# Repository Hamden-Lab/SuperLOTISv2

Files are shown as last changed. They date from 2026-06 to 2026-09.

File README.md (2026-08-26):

# SuperLOTISv2
Repo containing code for SuperLOTIS upgrade (SOPHIA camera, Pfeiffer Vacuum Pump and INFICON Vacuum Gauge)

## TODO
- [X] correct the bug at initialization of clients
- [] reimplement email in except error management in report_loop method
- [] fits image header not populated as expected
- [] test to take dark once again

## Issues
- KS : SOPHIA camera does not work through the StarTech USB Hub. Probable cause(s): https://chatgpt.com/s/t_6a70db7d7ffc81919d7addffe3072537, but works through the single 15ft USB3.0 cable. Needs to buy another one I guess.

## Architecture
* Python scripts to control/command/communicate with devices directly are located in `drivers/`
* Intermediate socket-based interface are located in `clients/`
* Constants and other useful functions are located in `tools/`

## Requirements
* Miniconda + Python 3.14
* opcua: for the Pfeiffer Vacuum Pump
* pyserial: for the INFICON
* pylablib: for the SOPHIA camera
* paramiko: SSH session
* typing-extensions
* keyring
* astropy
* influxdb3-python
* influxdb3 : database for status storage
* grafana : service for monitoring purposes

## Create the conda environment from file
```
conda env create -f environment.yml
```
If new packages have been installed, export again the current env configuration to file:
```
conda export > environment.yml
```

## Activate the conda environment
```
conda activate superlotis
```

## Reinstall the package
```
pip install -e .
```

## TODO
- [] write a sample scheduler script to test with our local devices (pdu + pump...)
- [] testing the camera chiller driver
- [] manage the timing of the scheduler lines now, now + 30, etc.
- [X] why apache2 server installation has root access required to edit php pages ? fixed wit sladm user
- [] remember to include outlet address for all items on PDU to constants.py
- [] write a windows bat file script that create a bunch of CMD terminals for each device driver + client with colours and paths
- [] get attribute names for SOPHIA
- [] implement shutter/dark taking for SOPHIA.py
- [X] set up NTP time server for PDU in order to have correct timing for logs
- [X] timeout of pdu is only 10 minutes max before logging off (see page 63 timeout). KS extend it to 10 minutes from the default 3 minutes.
- [X] send attributes update to slotis status server
- [X] find a way to end the threads properly (both socket server and polling) 
- [X] how to keep data persistent on the scheduler socket server ?

## SLOTIS sockets architecture

- `scheduler_loader.pl` : reading the schedule scripts and sending it to the scheduler host server ran in slotis_scheduler.pl
- `slotis_scheduler.pl` : hosting all the commands that need to be executed during the observation night.
- `device_client.pl/py` : sending status information to the slotis_status_server + interpreting and transfering commands read from the slotis_scheduler (smart way = identifying FLAG + managing the execution time by comparing it with now to what is contained in the scheduler line) host server to the actual device through serial or ethernet.

## Scheduler script sample

```perl
# Specify the exact local time of execution
# as: second minute hour day_of_month month year offset_in_seconds,
# then include the command.
# e.g., "12 10 18 13 11 2004 0 SLOTIS TCS NEXTRA +183210.0" would be executed at Sat Nov 13 18:10:12 2004
# while "12 10 18 13 11 2004 21 SLOTIS TCS NEXTRA +183210.0" would be executed at Sat Nov 13 18:10:43 2004

# A negative offset is also possible.
# e.g.,  "12 10 18 13 11 2004 -3 SLOTIS TCS NEXTRA +183210.0" would be executed at Sat Nov 13 18:10:09 2004
} elsif ( $line =~ /(\d+)\s+(\d+)\s+(\d+)\s+(\d+)\s+(\d+)\s+(\d+)\s*([\-|\s])(\d+)\s+(.+)/ ) {
$sec = $1;
$min = $2;
$hour = $3;
$mday = $4;               # Day of the month
$mon = $5 - 1;            # Months from Time::Local are 0 to 11, this changes the range from 1 to 12 to 0 to 11.
$year = $6;
$sign = $7;
$offset_secs = $8;
$cmd = $9;
$offset_secs = 0 - $offset_secs if $sign =~ /\-/;

$unix_timestamp = timelocal($sec, $min, $hour, $mday, $mon, $year) + $offset_secs;
```

```bash
#Observing schedule for 230518
now -1 SLOTIS SICAM cooler on
now 0 SLOTIS TCS 4 MOVSTOW
now 1 SLOTIS TCS 4 DISEPOCH 2000.0
0 31 19 18 05 2023 -20 SLOTIS TCS 0 ELAZ 85.00 180.00
0 31 19 18 05 2023 -10 SLOTIS TCS 0 TRKON
0 31 19 18 05 2023 0 SLOTIS FILTER position 1
0 31 19 18 05 2023 1 SLOTIS SICAM object Flat_B
0 31 19 18 05 2023 41 SLOTIS SICAM setexp 2000
0 31 19 18 05 2023 44 SLOTIS SICAM expose
0 31 19 18 05 2023 67 SLOTIS SICAM wfits /home/slotis/data/230518/flat001.fits
0 31 19 18 05 2023 88 SLOTIS TCS 0 stepra 100
0 31 19 18 05 2023 98 SLOTIS SICAM setexp 3000
0 31 19 18 05 2023 101 SLOTIS SICAM expose
0 31 19 18 05 2023 125 SLOTIS SICAM wfits /home/slotis/data/230518/flat002.fits
0 31 19 18 05 2023 146 SLOTIS TCS 0 stepra 100
0 31 19 18 05 2023 156 SLOTIS SICAM setexp 3000
0 31 19 18 05 2023 159 SLOTIS SICAM expose
0 31 19 18 05 2023 183 SLOTIS SICAM wfits /home/slotis/data/230518/flat003.fits
0 31 19 18 05 2023 204 SLOTIS TCS 0 stepra 100
0 31 19 18 05 2023 214 SLOTIS SICAM setexp 4000
0 31 19 18 05 2023 217 SLOTIS SICAM expose
0 31 19 18 05 2023 242 SLOTIS SICAM wfits /home/slotis/data/230518/flat004.fits
0 31 19 18 05 2023 263 SLOTIS TCS 0 stepra 100
0 31 19 18 05 2023 273 SLOTIS SICAM setexp 5000
0 31 19 18 05 2023 276 SLOTIS SICAM expose
0 31 19 18 05 2023 302 SLOTIS SICAM wfits /home/slotis/data/230518/flat005.fits
0 31 19 18 05 2023 323 SLOTIS TCS 0 stepra 100
0 31 19 18 05 2023 333 SLOTIS FILTER position 2
0 31 19 18 05 2023 334 SLOTIS SICAM object Flat_V
0 31 19 18 05 2023 374 SLOTIS SICAM setexp 3000
0 31 19 18 05 2023 377 SLOTIS SICAM expose
```

### SOPHIA get all attributes response

```python
Dictionary('ADC Analog Gain': High
'ADC Bit Depth': 16
'ADC Quality': Low Noise
'ADC Speed': 1.0
'Active Bottom Margin': 3
'Active Height': 2048
'Active Left Margin': 50
'Active Right Margin': 50
'Active Shutter': None
'Active Top Margin': 2
'Active Width': 2048
'CCD Characteristics': Back Illuminated & U.V. Enhanced & Multi-Port
'Clean Cycle Count': 1
'Clean Cycle Height': 2048
'Clean Serial Register': True
'Clean Until Trigger': True
'Cooling Fan Status': On
'Correct Pixel Bias': True
'Disable Cooling Fan': False
'Disable Data Formatting': False
'Exact Readout Count Maximum': 1000000000000
'Exposure Time': 100.0
'External Shutter Status': Not Connected
'External Shutter Type': Vincent CS45
'Frame Rate Calculation': 0.22867631860928136
'Frame Size': 8388608
'Frame Stride': 8388608
'Frame Tracking Bit Depth': 64
'Frames per Readout': 1
'Gap Height': 0.0
'Gap Width': 0.0
'Internal Shutter Status': Not Connected
'Internal Shutter Type': Vincent CS45
'Invert Output Signal': False
'Invert Output Signal-2': False
'Kinetics Window Height': 10
'Online Readout Rate Calculation': 0.23402798440173528
'Orientation': Normal
'Output Signal': Exposing
'Output Signal-2': Reading Out
'Pixel Bit Depth': 16
'Pixel Format': Monochrome 16-bit
'Pixel Height': 13.5
'Pixel Width': 13.5
'ROIs': [CPicamRoi(x=0, width=2048, x_binning=1, y=0, height=2048, y_binning=1)]
'Readout Control Mode': Full Frame
'Readout Count': 1
'Readout Orientation': Normal
'Readout Port Count': 1
'Readout Rate Calculation': 0.22867631860928136
'Readout Stride': 8388608
'Readout Time Calculation': 4272.99326
'Sensor Active Bottom Margin': 3
'Sensor Active Extended Height': 0
'Sensor Active Height': 2048
'Sensor Active Left Margin': 50
'Sensor Active Right Margin': 50
'Sensor Active Top Margin': 2
'Sensor Active Width': 2048
'Sensor Masked Bottom Margin': 0
'Sensor Masked Height': 0
'Sensor Masked Top Margin': 0
'Sensor Secondary Active Height': 0
'Sensor Secondary Masked Height': 0
'Sensor Temperature Reading': 19.0
'Sensor Temperature Set Point': 25.0
'Sensor Temperature Status': Unlocked
'Sensor Type': CCD
'Shutter Closing Delay': 0.0
'Shutter Delay Resolution': 1000.0
'Shutter Opening Delay': 0.0
'Shutter Timing Mode': Normal
'Time Stamp Bit Depth': 64
'Time Stamp Resolution': 10000000
'Time Stamps': None
'Track Frames': False
'Trigger Determination': Rising Edge
'Trigger Response': No Response
'Vertical Shift Rate': 12.0)
```

### Populate the headers of FITS images taken by SOPHIA from the status server

INSTRUMENT = 'SuperLOTIS telescope'
CCDNAME = 'Princeton Instruments E2V'
CCDTEMP
CCDTARGETTEMP
CHILLERTEMP
PUMP_PRESSURE
CAM_PRESSURE
VACUUM_VALVE
PDU_OUT1...
EXPTIME
DATE-OBS
MJD
FILTER
MOUNTRA
MOUNTDEC
MOUNTHA
MOUNTALT
MOUNTAZ
OBJECT
AIRMASS
WEATHER_...
CCDGAIN
BINNING
SHUTTER_STATUS
IMTYPE : light, dark, bias, flat...

+ all the attributes from SOPHIA with cam.get_all_attribute_values()

## Forward status and scheduler ports

ssh -L 5134:localhost:5134 -L 5135:localhost:5135 slotis@slotis.kpno.noirlab.edu

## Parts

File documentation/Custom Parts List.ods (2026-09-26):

Part | Material | Tolerance | Surface finish | Quantity | Drawing filename | Modify existing part? | Notes
Shutter controller plate | Aluminum 6061 | 0.01”, 0.002” for bolt holes | Deburred, as machined | 1 | shutter_controller_plate.pdf | N
LRS75 and USB hub plate | Aluminum 6061 | 0.01”, 0.002” for bolt holes | Deburred, as machined | 1 | lrs75_plate.pdf | N
90 deg breadboard bracket | Aluminum 6061 | 0.01”, 0.002” for bolt holes | Deburred, as machined | 4 | 90deg_bracket_tslot.pdf | N
Side breadboard bracket | Stainless steel | 0.01”, 0.002” for bolt holes | Deburred, as machined | 3 | side_bracket_tslot.pdf | N
Filter interface | Aluminum 6061 | 0.01”, 0.002” for bolt holes | Deburred, as machined | 1 | Filter_Interface_REAL.pdf | Y | Already exist, we bring it
G10 plate | Garolite G10 | 0.01”, 0.002” for bolt holes | Deburred, as machined | 1 | g10_camera_isolation_plate.pdf | Y | We bring the raw material
For questions, contact:
hmbradley1@arizona.edu
sommerk@arizona.edu

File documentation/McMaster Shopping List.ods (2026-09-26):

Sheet: Framing
 |  |  | McMaster ref. | From 8020 | Name 8020 | Comment
Count | Item | Length (in) | ID | No.
2 | Double | 12 | 47065T472 | 1020-Black | 1.00” X 2.00” T-Slotted Profile - Six Open T-Slots | Tap the holes 1/4-20
2 | Double | 38 |  | 1020-Black | 1.00” X 2.00” T-Slotted Profile - Six Open T-Slots | Tap the holes 1/4-20
Total Double | Double | 100
5 | Single | 10 | 47065T1 | 1010-Black | 1.00” X 1.00” T-Slotted Profile - Four Open T-Slots | Tap the holes 1/4-20
12 | Single | 12 | 47065T503 | 1010-Black | 1.00” X 1.00” T-Slotted Profile - Four Open T-Slots | Tap the holes 1/4-20
Total Single | Single | 194

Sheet: Brackets
Cage Assembly |  | McMaster ref. | From 8020 | Name 8020 | Comment
Count | Item | ID | No.
2 | Double L Bracket | 47065T562 | 4128-Black | 10 Series 12 Hole - 90 Degree Angled Flat Plate | Need to add fasteners
8 | 1x1 corner bracket | 47065T377 | 4265-Black | 10 Series 2 Hole - Slotted Inside Corner Bracket | Need to add fasteners
4 | 6” single diagonal brace | 47065T451 | 2565-Black | 1010-Black 45 Degree Support, 6" Long | Fasteners included
26 | 2Lx1W gusset | 47065T749 | 4136-Black | 10 Series 4 Hole - Tall Gusseted Inside Corner Bracket | Need to add fasteners
2 | 12” single diagonal brace | 47065T452 | 2570-Black | 1010-Black 45 Degree Support, 12" Long | Fasteners included
4 | T-Slotted Framing Black Straight Surface Bracket, 2" Long for 1" High Rail | 47065T832 | 4107-Black | 10 Series 2 Hole - Straight Flat Plate | Need to add fasteners
2 | T-Slotted Framing Black Surface Bracket, 4" Long for 1" High Single Rail | 47065T313 | 4117-Black | 10 Series 4 Hole - Straight Flat Plate | Need to add fasteners
Shutter Assembly Att.
2 | 1x1 corner bracket | 47065T377 | 4265-Black | 10 Series 2 Hole - Slotted Inside Corner Bracket | Need to add fasteners

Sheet: Fasteners
Camera Sub-assembly
Number | Screw | ID | Pack size
6 | 1/4”-20x1.5” HS | 96006A727 | 10
4 | 6-32x3/4” | 92196A151 | 100
6 | ¼” washer Narrow | 90313A203 | 50
20 | ¼” washer | 92141A029 | 100
6 | Nylon Flat Edge Insulating Sleeve Washers | 91145A222 | 100
1 | 3225T63_Vibration-Damping Loop Clamp | 3225T63 | 5 | Alternative is aluminum = 3177T11
Cage Assembly
Number | Screw
60 | T-slot Nut | 6000N501 | 4
Turbo Assembly
Number | Screw
6 | 1/4”-20x0.5” (socket head) | 92196A537 | 50 | HAVE
2 | 1/4”-20x5/8” |  |  | HAVE
4 | M5x16mm | 91292A126 | 100
Powerpak Assembly
Number | Screw
4 | 1/4”-20x0.5” (socket head) | 92196A537 | 50 | HAVE
Shutter Power USB Assembly
4 | Corrosion-Resistant 18-8 Stainless Steel Female Threaded Hex Standoff 1/4" Hex Size, 3-1/2" Long, 10-32 Thread Size | 91115A840 | 1
4 | 10-32x0.5” |  |  | HAVE
4 | 1/4”-20x0.75” |  |  | HAVE
MVP Assembly
4 | Vibration-Damping Sandwich Mount | 9376K36 | 1 | Need to cut one side of the male thread to fit in the T-slot groove
4 | High-Strength Steel Nylon-Insert Locknut | 97135A210 | 25

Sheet: Miscellaneous
Vacuum electrical insulation
1 | Edwards Swing Clamp, KF 16 (NW 16), Polymer, C10512304 | Edwards Swing Clamp, KF-16 (NW-16), Polymer Vacuum Clamp, C10512304, C105-12-304,Edwards Swing Clamp, KF-16 (NW-16), Polymer Vacuum Clamp, C10512304, C105-12-304 (https://www.ajvs.com/edwards-swing-clamp-23876)
1 | Pfeiffer Centering Ring KF-16 Vacuum Fittings, ISO-KF Flange Size NW-16, PTFE & Viton O-Ring. PN: 132ZRG016 | Ideal Vacuum | Pfeiffer Centering Ring KF-16 Vacuum Fittings, ISO-KF Flange Size NW-16, PTFE & Viton O-Ring. PN: 132ZRG016. (https://www.idealvac.com/en-us/Pfeiffer-Centering-Ring-KF-16-Vacuum-Fittings-ISO-KF-Flange-Size-NW-16-PTFE-Viton-O-Ring-PN:-132ZRG016/pp/P1012264)

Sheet: Custom parts
Custom Items
Camera Assembly |  |  | Drawings | Make at GS
Count | Item | Note
1 | tubing support frame | Strong 3D printed material
1 | Filter interface | Machine new holes + widen to fit the insulation sleeves to 0.312” at least | Kelian | Y
1 | G10 plate |  | Kelian | Y
Turbo Assembly
Count | Item
1 | Turbo_mounting_bracket | Aluminum machining + 3d print for circular shape | Harrison | Y
1 | Turbo_bottom_bracket | Aluminum machining | Harrison | Y
Cage Assembly
Count | Item
3 | side_bracket_tslot | Do we need stainless steel or alu is strong enough? | Kelian | Y
4 | 90deg_bracket_tslot | Buy a aluminum cube, cut in half and then CNC machine? | Kelian | Y
 | Tap 1/4”-20 holes in all of them |  |  | Y
Pump Electronics Assembly
Count | Item
4 | Tap 1/4”-20 holes in bottom |  |  | Y
Powerpak Assembly
2 | TELEDYNE_POWERPAK_BRACKET_V3 | Strong 3D printed material |  | N
Shutter Power USB Assembly
1 | shutter_controller_plate | Aluminum machining | Kelian | Y
1 | lrs75_plate | Aluminum machining | Kelian | Y
Enclosure
? | Clear Scratch- and UV-Resistant Cast Acrylic Sheet 24" x 24" x 1/8" | 85635K481 | Clear acrylic sheet or opaque PVC? What about blocking IR for the camera?

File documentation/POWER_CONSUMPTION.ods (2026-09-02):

Item | Ref. of device or PSU | Max power (W) | PDU outlet #
Following items are plugged into the YPS SRT1500RMXLA 1350W
Telescope mount |  | ? | N.A
Should we get a UPS for these two also ?
lyman computer | Dell Vostro 5890 | 460 | N.A
Camera power supply | SOPHIA Teledyne Powerpak | 410 | N.A
Following items are plugged into the PDU41001
INFICON gauge for camera | Meanwell LRS-50-24 | 50 | 3
INFICON gauge for pump | Meanwell LRS-50-24 | 50 | 4
ElectroMAG Vacuum valve | Meanwell LRS-75-24 | 75 | 2
Shutter controller | Uniblitz VCM-D1 | 60 | 8
Startech USB HUB ST1030USBM | Meanwell LRS-75-24 | 75 | 5
Vacuum pumps | Pfeiffer HiCube 80 Neo | 205 | 6
Camera chiller | TCube edge 10-14072-4S-1 | 850 | 7
 | Total (max) on PDU41001 | 1365
 | PDU rated for 1440W max

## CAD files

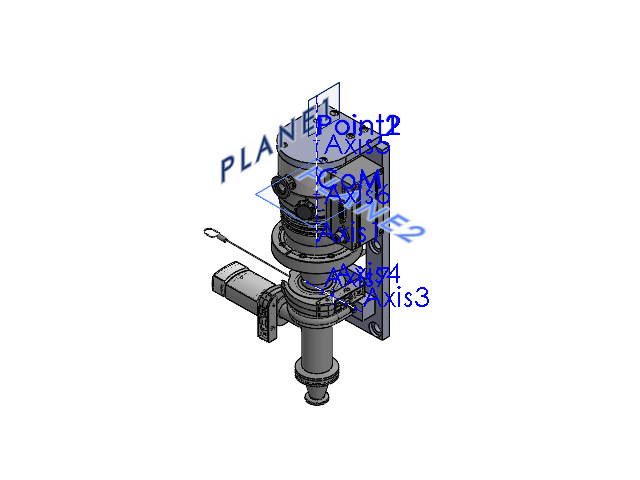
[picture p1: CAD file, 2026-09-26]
documentation/CAD/Turbo_bracket_assembly.SLDASM
Pfeiffer_HiPace_80_with_ISO63_PMP03940_Step_File.step
Turbo_mounting_bracket
Turbo_bottom_bracket
4518K614_Quick-Clamp High-Vacuum Fitting
4518K817_O-Ring with Stainless Steel Screen for 1-1-2 Tube OD Quick-Clamp High-Vacuum Fitting x 2
4518K522_Quick-Clamp High-Vacuum Fitting
3176T14_Vibration-Damping U-Bolt
4518K967_Lever Clamp with Lanyard
4518K621_Fluoroelastomer Rubber O-Ring for 3-4 Tube OD Quick-Clamp High-Vacuum Fitting
MPCG55x_15DSub_16KF.stp
4518K965_Lever Clamp with Lanyard
4518K291_Quick-Clamp High-Vacuum Fitting
socket head cap screw_am x 5
socket head cap screw_ai x 2

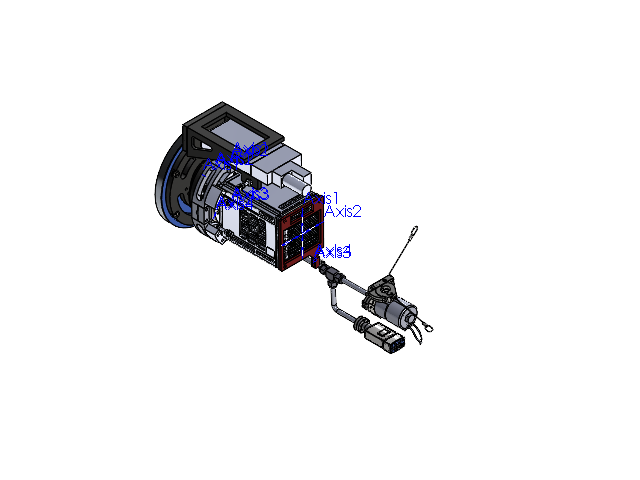
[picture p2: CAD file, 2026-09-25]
documentation/CAD/camera_assembly/UArizona_Superlotis_Assembly.SLDASM
Bracket
Filter_Interface_REAL
Interacing_Plate_LinearStage_to_FixtureHolder
LinearStage
LinearStage_Moving_Plate
Cosmetic_Flap x 4
OuterAssembly_Flexture_Holder_Long_End
OuterAssembly_Flexture_Holder_Short_End
OuterAssembly
teflon washer
AdjustmentScrew x 4
AdjustmentScrew_Mount x 2
AdjustmentScrew_ThreadBody x 4
Q27031-1 University of Arizona1(2)^custom_viewport_correct
custom_viewport_main
Q27031-1 University of Arizona3(2)^custom_viewport_correct
cs45-unhoused-3d-model1^cs45-unhoused-3d-model(2)_cs45-unhoused-3d-model
cs45-unhoused-3d-model2^cs45-unhoused-3d-model(2)_cs45-unhoused-3d-model
cs45-unhoused-3d-model3^cs45-unhoused-3d-model(2)_cs45-unhoused-3d-model
cs45-unhoused-3d-model4^cs45-unhoused-3d-model(2)_cs45-unhoused-3d-model
cs45-unhoused-3d-model5^cs45-unhoused-3d-model(2)_cs45-unhoused-3d-model
cs45-unhoused-3d-model6^cs45-unhoused-3d-model(2)_cs45-unhoused-3d-model
cs45-unhoused-3d-model7^cs45-unhoused-3d-model(2)_cs45-unhoused-3d-model
cs45-unhoused-3d-model8^cs45-unhoused-3d-model(2)_cs45-unhoused-3d-model
cs45-unhoused-3d-model9^cs45-unhoused-3d-model(2)_cs45-unhoused-3d-model
cs45-unhoused-3d-model10^cs45-unhoused-3d-model(2)_cs45-unhoused-3d-model
cs45-unhoused-3d-model11^cs45-unhoused-3d-model(2)_cs45-unhoused-3d-model
cs45-unhoused-3d-model12^cs45-unhoused-3d-model(2)_cs45-unhoused-3d-model
cs45-unhoused-3d-model13^cs45-unhoused-3d-model(2)_cs45-unhoused-3d-model
cs45-unhoused-3d-model14^cs45-unhoused-3d-model(2)_cs45-unhoused-3d-model
cs45-unhoused-3d-model15^cs45-unhoused-3d-model(2)_cs45-unhoused-3d-model
cs45-unhoused-3d-model16^cs45-unhoused-3d-model(2)_cs45-unhoused-3d-model
cs45-unhoused-3d-model17^cs45-unhoused-3d-model(2)_cs45-unhoused-3d-model
cs45-unhoused-3d-model18^cs45-unhoused-3d-model(2)_cs45-unhoused-3d-model
cs45-unhoused-3d-model19^cs45-unhoused-3d-model(2)_cs45-unhoused-3d-model
cs45-unhoused-3d-model20^cs45-unhoused-3d-model(2)_cs45-unhoused-3d-model
cs45-unhoused-3d-model21^cs45-unhoused-3d-model(2)_cs45-unhoused-3d-model
cs45-unhoused-3d-model22^cs45-unhoused-3d-model(2)_cs45-unhoused-3d-model
cs45-unhoused-3d-model23^cs45-unhoused-3d-model(2)_cs45-unhoused-3d-model
cs45-unhoused-3d-model24^cs45-unhoused-3d-model(2)_cs45-unhoused-3d-model
cs45-unhoused-3d-model25^cs45-unhoused-3d-model(2)_cs45-unhoused-3d-model
cs45-unhoused-3d-model26^cs45-unhoused-3d-model(2)_cs45-unhoused-3d-model
cs45-unhoused-3d-model27^cs45-unhoused-3d-model(2)_cs45-unhoused-3d-model
cs45-unhoused-3d-model28^cs45-unhoused-3d-model(2)_cs45-unhoused-3d-model
cs45-unhoused-3d-model29^cs45-unhoused-3d-model(2)_cs45-unhoused-3d-model
cs45-unhoused-3d-model30^cs45-unhoused-3d-model(2)_cs45-unhoused-3d-model
cs45-unhoused-3d-model32^cs45-unhoused-3d-model(2)_cs45-unhoused-3d-model
cs45-unhoused-3d-model33^cs45-unhoused-3d-model(2)_cs45-unhoused-3d-model
Flagen_adpater_L_2 x 2
6035-0004 SOPHIA-XO 2048 6 inch_1-300_Long.STEP_1 x 2
2517- 6-00 Conflat SOPHIA-XO 2048 6 inch-0.STEP_1
2825-0587 SOPHIA-XO 2048 6 inch.STEP_1 x 3
2825-0395-FLANGE SOPHIA-XO 2048 6 inch.STEP_1
2825-0395-SEAL SOPHIA-XO 2048 6 inch.STEP_1
Conflat 6-00 Nose SOPHIA-XO 2048 6 inch.STEP_1
CCD-230-42_2048x2048 SOPHIA-XO 2048 6 inch.STEP_1
PIXIS-II X-Ray Mask Large Array SOPHIA-XO 2048 6 inch.STEP_1
X-Ray Mask Large Array Clamp SOPHIA-XO 2048 6 inch.STEP_1
SCREW,FLAT HD,SLOT,VENTED,#2-56 x 0.1875,18-8 ST-STL SOPHIA-XO 2048 6 inch_2826-XXXX.STEP_1 x 4
2100-0678 SOPHIA-XO 2048 6 inch.STEP_1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

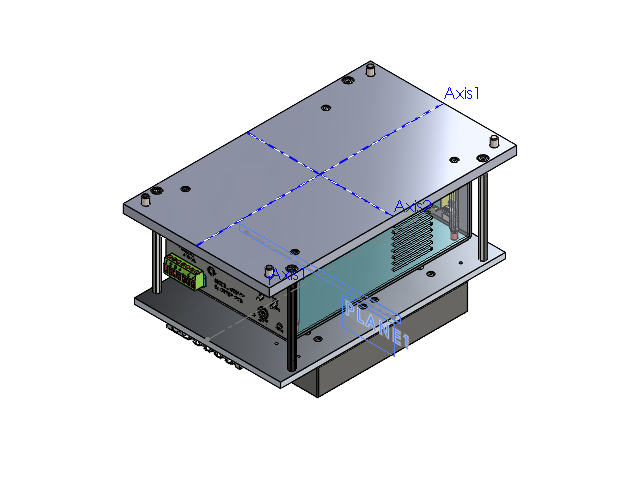
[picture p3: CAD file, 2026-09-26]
documentation/CAD/shutter_power_usb_assembly_V2.SLDASM
shutter_controller_plate
Slideswitchspdt2.STEP x 8
Keyswitch_Assembly.STEP
5-pinharness_9-pin.STEP
Keyswitchcable_Short.STEP
Cabletie_2wires short.STEP
VCM-D1fpsilk.STEP
Logo_Scale VCM-D1.STEP
Rochester.STEP
VA.STEP
VCM-D1_1.STEP
New logo 3D_VDM1000.STEP
VCM-D1case_With rp stud.STEP
BNC.STEP x 6
BNCnut.STEP x 6
groundlug.STEP x 6
Corcompower_115 V Closed.STEP
BNCgroundlug_Trimmed.STEP
Ledclip.STEP x 4
Keyswitchnut.STEP
Foot.STEP x 4
VCM-D1spacer.STEP
VCM-D1rpsilk.STEP
VCM-D1serialnolabel.STEP
VCM-D1metlabel.STEP
SwitchcraftTiniQG.STEP
3-48 x .1875 FH_CR-FHMS 0.099-48x0.188x0.188-S.STEP x 2
1-2-20hexnut_.255thick.STEP
6-32 Nut Hex_.109 thick.STEP x 2
Led.STEP x 4
Terminalsocket_7.STEP
Octalswitch.STEP
Inout.STEP
Fuseholderbottom.STEP
Corcom Fuse.STEP
Fuseholdercap.STEP
Switch_D3-D4.STEP x 2
Switch_D1-T1.STEP
Poststripplug_7.STEP
VCM-D1alignmentpl.STEP
VCM-D1cover.STEP
6-32mfstandoff.STEP x 4
Washer.STEP x 4
Corcomlabel.STEP
91115A840_Corrosion-Resistant 18-8 Stainless Steel Female Threaded Hex Standoff x 4
lrs75_plate
User Library-LRS-35,50 Mean Well_Bot LRS-75___ _________.STEP x 2
User Library-LRS-35,50 Mean Well_Cap LRS-75___ _________.STEP x 2
User Library-LRS-35,50 Mean Well_PCB LRS-75___ _________.STEP x 2
User Library-LRS-75 Mean Well_Terminal Block LRS-35,50___ _________.STEP x 2
st1030usbm.stp
socket head cap screw_ai x 16
flat washer type a narrow_ai x 4
socket head cap screw_am x 10

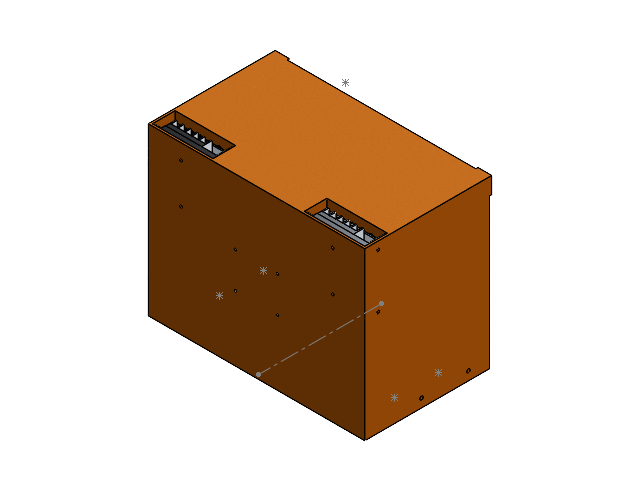
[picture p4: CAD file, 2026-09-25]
documentation/CAD/pump_electronics_assembly_1.SLDASM
pfeiffer_electronics_cover
LRS-50-24.step x 2
pfeiffer_electronics_lower_edge

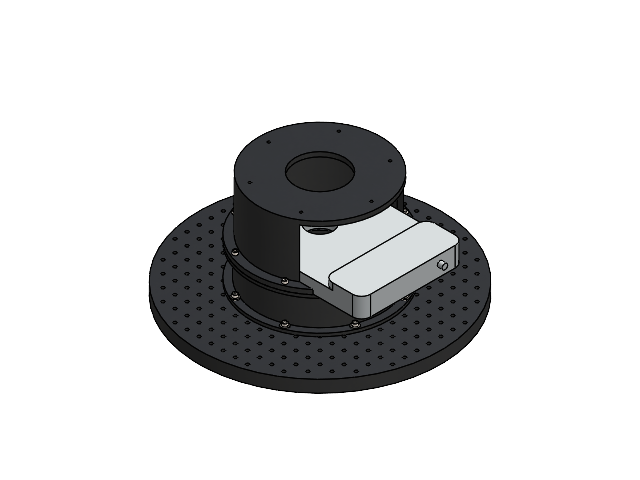
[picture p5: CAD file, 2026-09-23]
documentation/CAD/baseplate_assembly.SLDASM
breadboard_plate_blank
base_upper_plate
base_plate
filter_wheel
socket head cap screw_ai x 14
flat washer type a narrow_ai x 8

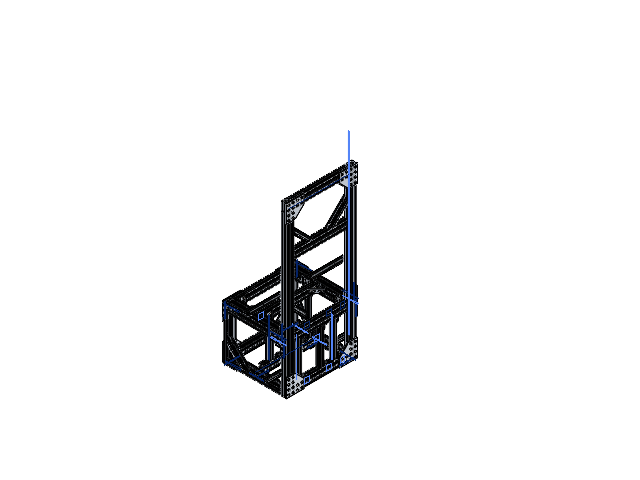
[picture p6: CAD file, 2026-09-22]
documentation/CAD/CAGE_SUBASSEMBLY_V25.SLDASM
47065T472_T-Slotted Framing x 12
47065T489_T-Slotted Framing x 2
6575N477_T-Slotted Framing Rail x 2
47065T489_T-Slotted Framing_2in x 2
47065T1_T-Slotted Framing_8in x 5
47065T562_T-Slotted Framing x 8
3136N157_T-Slotted Framing x 9
3136N159_T-Slotted Framing x 2
3136N171_T-Slotted Framing x 8
47065T451_Black Diagonal Brace x 8
47065T461_T-Slotted Framing x 2
47065T736_Silver Gusset Bracket x 10
socket button head cap screw_ai x 212

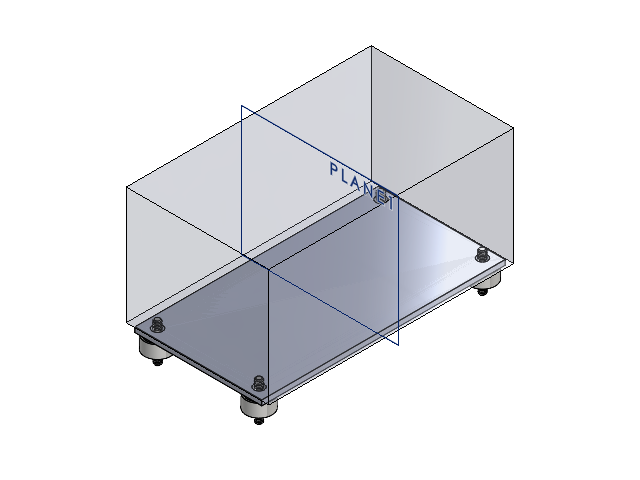
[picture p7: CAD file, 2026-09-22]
documentation/CAD/MVP_ASSEMBLY.SLDASM
PFEIFFER_MVP_FOOTPRINT
SUPPORT_PLATE_MVP
9376K36_Vibration-Damping Sandwich Mount x 4

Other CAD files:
documentation/CAD/camera_assembly/SOPHIA-XO_2048/2410-0258 SOPHIA-XO 2048 6 inch.STEP_1.SLDASM
documentation/CAD/camera_assembly/SOPHIA-XO_2048/PLACEHOLDER 7596 Product Name Label SOPHIA-XO 2048 6 inch_2410-0258.STEP_1.SLDASM
documentation/CAD/camera_assembly/custom_viewport_correct.SLDASM
documentation/CAD/camera_assembly/SOPHIA-XO_2048/2410-0257 SOPHIA-XO 2048 6 inch.STEP_1.SLDASM
documentation/CAD/camera_assembly/LinearStage_Assembly.SLDASM
documentation/CAD/camera_assembly/SOPHIA-XO_2048/2100-0685 SOPHIA-XO 2048 6 inch.STEP_1.SLDASM
documentation/CAD/camera_assembly/SOPHIA-XO_2048/PLACEHOLDER 7596 Array Label SOPHIA-XO 2048 6 inch_2410-0241.STEP_1.SLDASM
documentation/CAD/camera_assembly/SOPHIA-XO_2048/1750-0903 SOPHIA-XO 2048 6 inch.STEP_1.SLDASM
documentation/CAD/camera_assembly/SOPHIA-XO_2048/PIXIS-II 6-00 Conflat Tap US Thread SOPHIA-XO 2048 6 inch.STEP_1.SLDASM
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

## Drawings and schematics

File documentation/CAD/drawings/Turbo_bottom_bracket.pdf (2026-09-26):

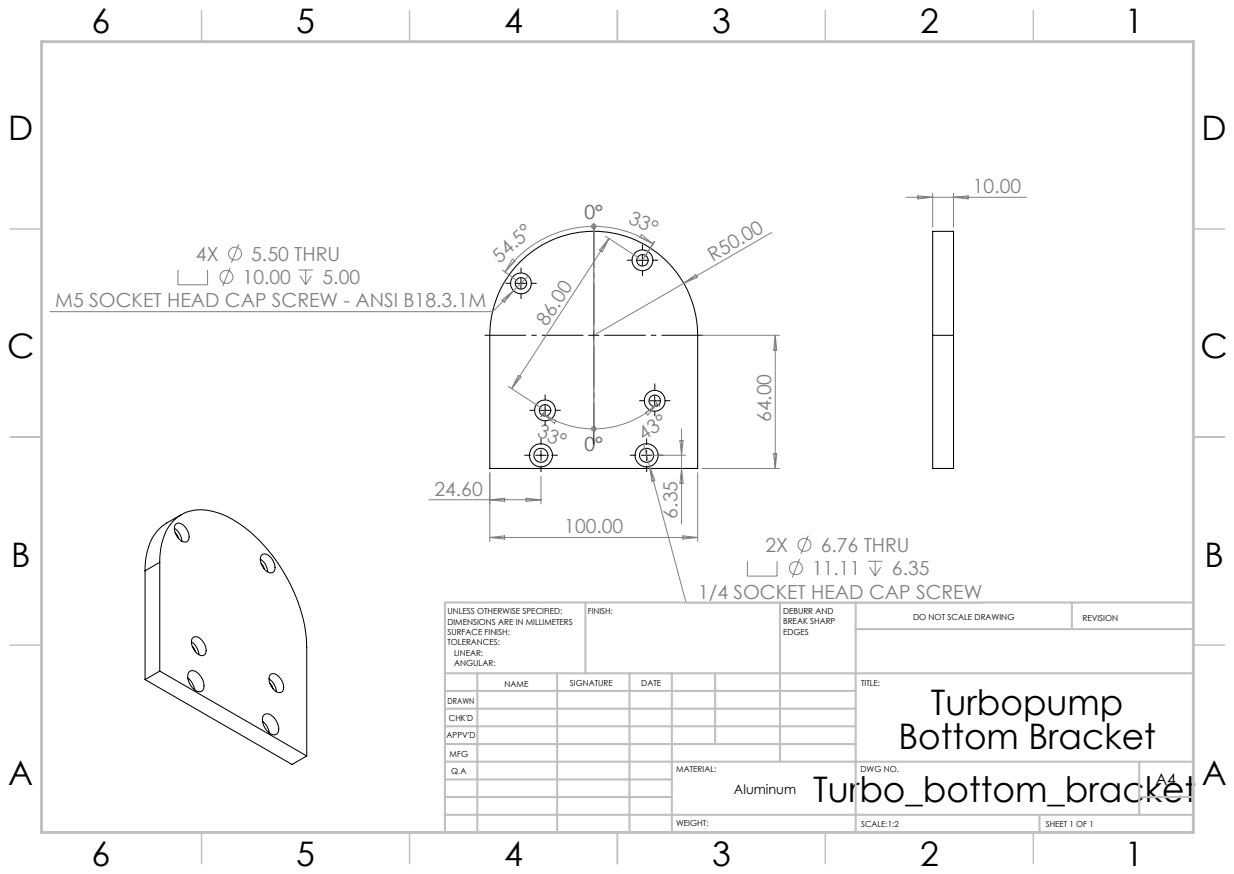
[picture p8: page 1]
5.50 THRU; 6.76 THRU; FINISH:; DEBURR AND; BREAK SHARP; DO NOT SCALE DRAWING; REVISION; SCALE:1:2; SHEET 1 OF 1

M5 SOCKET HEAD CAP SCREW - ANSI B18.3.1M

1/4 SOCKET HEAD CAP SCREW 64.00

UNLESS OTHERWISE SPECIFIED:
DIMENSIONS ARE IN MILLIMETERS
SURFACE FINISH:
TOLERANCES:
LINEAR:
ANGULAR:

NAME | SIGNATURE | DATE | | | | TITLE: Turbopump Bottom Bracket

DRAWN
CHK'D
APPV'D
MFG
Q.A | | | | MATERIAL: Turbo_bottom_bracket | DWG NO. | A4 Aluminum

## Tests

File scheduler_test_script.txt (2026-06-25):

#Test scheduler for SOPHIA upgrade
now 0 LYMAN PDU poweroff 2
now 5 LYMAN PDU get status 2
now 10 LYMAN PDU poweron 2
now 15 LYMAN PUMP 
now 20 LYMAN

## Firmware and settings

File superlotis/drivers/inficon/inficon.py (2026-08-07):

import serial
import serial.tools.list_ports
from serial.tools import list_ports
import struct
from typing import Dict, Optional
import time
from superlotis.tools.constants import PSG550_SERIAL_NUMBER, PCG550_SERIAL_NUMBER

class PxG55xRS485:
    """
    Driver for INFICON PCG550/552/554 and PSG550/552/554 RS485 interface.
    https://www.inficon.com/en/products/vacuum-gauge-and-controller/pcg55x
    """

    DEVICE_ID_MASTER = 0x00

    CMD_READ_REQ = 0x01
    CMD_READ_RESP = 0x02
    CMD_WRITE_REQ = 0x03
    CMD_WRITE_RESP = 0x04

    def __init__(
        self,
        port,
        baudrate=57600,
        timeout=2.0,
        bytesize=serial.EIGHTBITS,
        parity=serial.PARITY_NONE,
        stopbits=serial.STOPBITS_ONE,
        address=1,
        
    ):
        self.address = address
        self.port = port
        self.baudrate = baudrate
        self.timeout = timeout
        self.bytesize = bytesize
        self.parity = parity
        self.stopbits = stopbits

    def connect(self):
        self.ser = serial.Serial(
            port=self.port,
            baudrate=self.baudrate,
            timeout=self.timeout,
            bytesize=self.bytesize,
            parity=self.parity,
            stopbits=self.stopbits,
        )

    def disconnect(self):
        if self.ser is not None and self.ser.is_open:
            self.ser.close()

    def close(self):
        self.ser.close()

    # ------------------------------------------------------------------
    # CRC16 (same algorithm as in the documentation)
    # ------------------------------------------------------------------

    @staticmethod
    def crc16(data: bytes) -> int:
        crc = 0xFFFF

        for b in data:
            crc ^= b
            for _ in range(8):
                if crc & 1:
                    crc = (crc >> 1) ^ 0x8408
                else:
                    crc >>= 1

        return crc & 0xFFFF

    @classmethod
    def append_crc(cls, payload: bytes) -> bytes:
        crc = cls.crc16(payload)
        return payload + struct.pack("<H", crc)

    @classmethod
    def verify_crc(cls, frame: bytes):
        if len(frame) < 2:
            return False

        expected = struct.unpack("<H", frame[-2:])[0]
        actual = cls.crc16(frame[:-2])
        return expected == actual

    # ------------------------------------------------------------------
    # Low-level communication
    # ------------------------------------------------------------------

    def _send(self, frame):
        # print("TX:", frame.hex(" "))
        self.ser.reset_input_buffer()
        self.ser.write(frame)

    def _read_frame(self):
        # Read first 4-byte header
        header = self.ser.read(4)
        if len(header) != 4:
            raise TimeoutError("Timeout waiting for response header.")

        msg_len = header[3]

        # msg_len counts Cmd + PID + Reserved + Data
        remaining = msg_len + 2  # + CRC16
        body = self.ser.read(remaining)

        if len(body) != remaining:
            raise TimeoutError("Incomplete response.")

        frame = header + body

        if not self.verify_crc(frame):
            raise IOError("CRC check failed.")

        return frame

    # ------------------------------------------------------------------
    # Generic read/write
    # ------------------------------------------------------------------

    def read_pid(self, pid):
        payload = bytearray()

        payload.append(self.address)
        payload.append(self.DEVICE_ID_MASTER)
        payload.append(0x00)        # Ack
        payload.append(5)           # Cmd+PID+Reserved = 1+2+2

        payload.append(self.CMD_READ_REQ)
        payload.extend(struct.pack(">H", pid))
        payload.extend(b"\x00\x00")

        frame = self.append_crc(bytes(payload))

        self._send(frame)

        response = self._read_frame()

        cmd = response[4]
        if cmd != self.CMD_READ_RESP:
            raise IOError("Unexpected response command.")

        pid_returned = struct.unpack(">H", response[5:7])[0]
        if pid_returned != pid:
            raise IOError("Returned PID mismatch.")

        data = response[9:-2]

        return data

    def write_pid(self, pid, data: bytes):
        payload = bytearray()

        payload.append(self.address)
        payload.append(self.DEVICE_ID_MASTER)
        payload.append(0x00)

        msg_length = 5 + len(data)
        payload.append(msg_length)

        payload.append(self.CMD_WRITE_REQ)
        payload.extend(struct.pack(">H", pid))
        payload.extend(b"\x00\x00")
        payload.extend(data)

        frame = self.append_crc(bytes(payload))

        self._send(frame)

        response = self._read_frame()

        if response[4] != self.CMD_WRITE_RESP:
            raise IOError("Write failed.")

    # ------------------------------------------------------------------
    # Convenience methods
    # ------------------------------------------------------------------

    def get_pressure_real(self):
        """
        Read PID 222 (Real32 pressure).

        Returns:
            float : pressure in currently configured units.
        """
        data = self.read_pid(222)
        return struct.unpack(">f", data)[0]

    def get_pressure_fixed(self):
        """
        Read PID 221 (Fixs32en20 integer pressure).

        Returns pressure converted to float.
        """
        data = self.read_pid(221)
        raw = struct.unpack(">i", data)[0]
        return raw / (2 ** 20)

    def get_serial_number(self):
        data = self.read_pid(207)
        return struct.unpack(">I", data)[0]

    def get_product_name(self):
        data = self.read_pid(208)
        return data.decode("ascii").rstrip("\x00")

    def set_pressure_unit(self, unit):
        """
        PID 224

        unit:
            0 = mbar
            1 = Torr
            2 = Pascal
            3 = micron
            4 = Counts
        """
        self.write_pid(224, bytes([unit]))

    def is_open(self):
        return self.ser.is_open


def infer_gauge_label(product_name: str) -> Optional[str]:
    normalized = (product_name or "").strip().upper()
    if "PCG550" in normalized:
        return "PCG550"
    if "PSG550" in normalized:
        return "PSG550"
    return None


def discover_gauge_ports(port_candidates=None, timeout=2.0) -> Dict[str, str]:
    if port_candidates is None:
        ports = list(serial.tools.list_ports.comports())
        port_candidates = [port.device for port in ports]

    discovered: Dict[str, str] = {}
    for port in port_candidates:
        probe = None
        try:
            probe = PxG55xRS485(port=port, timeout=timeout)
            product_name = probe.get_product_name()
            label = infer_gauge_label(product_name)
            if label:
                discovered[label] = port
        except Exception:
            continue
        finally:
            if probe is not None:
                try:
                    probe.close()
                except Exception:
                    pass

    return discovered


if __name__ == "__main__":

    for port in list_ports.comports():
        print(port)
        if port.serial_number == PSG550_SERIAL_NUMBER:
            print(port)
            pump_gauge = PxG55xRS485(port=port.device)
            pump_gauge.connect()
        if port.serial_number == PCG550_SERIAL_NUMBER:
            camera_gauge = PxG55xRS485(port=port.device)
            camera_gauge.connect()

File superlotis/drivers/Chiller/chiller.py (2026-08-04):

import serial
from serial.tools import list_ports
from superlotis.tools.constants import CHILLER_SERIAL_NUMBER, CHILLER_SERIAL_BAUDRATE

class TCubeChiller:
    """
    Driver for the TCUBE Edge Thermoelectric Chiller over RS-232.

    Example
    -------
    >>> chiller = TCubeChiller("/dev/ttyUSB0")
    >>> chiller.connect()
    >>> print(chiller.get_temperature())
    >>> chiller.set_setpoint(20.0)
    >>> chiller.run()
    >>> status = chiller.get_status()
    >>> chiller.disconnect()
    """

    def __init__(
        self,
        port,
        baudrate=CHILLER_SERIAL_BAUDRATE,
        timeout=1.0,
        bytesize=serial.EIGHTBITS,
        parity=serial.PARITY_NONE,
        stopbits=serial.STOPBITS_ONE,
    ):
        self.port = port
        self.baudrate = baudrate
        self.timeout = timeout
        self.bytesize = bytesize
        self.parity = parity
        self.stopbits = stopbits

    def connect(self):
        self.ser = serial.Serial(
            port=self.port,
            baudrate=self.baudrate,
            timeout=self.timeout,
            bytesize=self.bytesize,
            parity=self.parity,
            stopbits=self.stopbits,
        )

    def disconnect(self):
        if self.ser is not None and self.ser.is_open:
            self.ser.close()

    @property
    def connected(self):
        return self.ser is not None and self.ser.is_open

    def _send(self, command):
        if not self.connected:
            raise RuntimeError("Serial port is not connected.")

        if not command.endswith("\r"):
            command += "\r"

        self.ser.reset_input_buffer()
        self.ser.write(command.encode("ascii"))
        self.ser.flush()

    def _query(self, command):
        self._send(command)
        return self.ser.readline().decode("ascii").strip()

    # ------------------------------------------------------------------
    # Basic commands
    # ------------------------------------------------------------------

    def identify(self):
        """Return identification string."""
        return self._query("IDN")

    def local(self):
        """Return control to local mode."""
        self._send("LOCAL")

    def start(self):
        """Start the chiller."""
        self._send("RUN")

    def stop(self):
        """Stop the chiller."""
        self._send("STOP")

    def restart(self):
        """Reset alarms and restart."""
        self._send("RESTART")

    # ------------------------------------------------------------------
    # Temperatures
    # ------------------------------------------------------------------

    def get_temperature(self):
        """Current coolant temperature (°C)."""
        return float(self._query("TEMP?"))

    def get_pump_temperature(self):
        """Pump temperature (°C)."""
        return float(self._query("PUMPTEMP?"))

    def get_setpoint(self):
        """Current setpoint (°C)."""
        return float(self._query("SETTEMP?"))

    def set_setpoint(self, temperature):
        """Set temperature setpoint (°C)."""
        self._send(f"SETTEMP {temperature:.1f}")

    def get_alarm_width(self):
        return float(self._query("WIDTH?"))

    def set_alarm_width(self, width):
        self._send(f"WIDTH {width:.1f}")

    def get_rtd_offset(self):
        return float(self._query("RTDOFFSET?"))

    def set_rtd_offset(self, offset):
        self._send(f"RTDOFFSET {offset:.1f}")

    # ------------------------------------------------------------------
    # Status
    # ------------------------------------------------------------------

    def get_run_state(self):
        """Returns 'RUNNING' or 'STOPPED'."""
        return self._query("RUN?")

    def get_pwm(self):
        """Current thermoelectric PWM (%).
        A minus symbol, - , will preceed negative temperature values or PWM% when cooling.
        """
        return float(self._query("PWM?"))

    def get_status(self):
        """Status word."""
        return int(self._query("STAT1A?"))

    def get_faults(self):
        """Fault word."""
        return int(self._query("FLTS1A?"))

    # ------------------------------------------------------------------
    # Display
    # ------------------------------------------------------------------

    def backlight_on(self):
        self._send("BLON")

    def backlight_off(self):
        self._send("BLOFF")

    # ------------------------------------------------------------------
    # Bulk read
    # ------------------------------------------------------------------

    def get_all(self):
        """
        Read all values using GETSET2.

        Returns
        -------
        dict
            {
                "temperature": float,
                "setpoint": float,
                "pump_temperature": float,
                "pwm": float,
                "fan_pwm": float,
                "tank_level_low": int,
                "status": int,
                "faults": int,
            }
        """
        self._send("GETSET2")

        # Read until ETX (0x03)
        raw = b""
        while True:
            b = self.ser.read(1)
            if not b:
                break
            if b == b"\x03":
                break
            raw += b

        fields = raw.decode("ascii").split("\r")
        fields = [f for f in fields if f]

        if len(fields) != 8:
            raise RuntimeError(
                f"Unexpected GETSET2 response ({len(fields)} fields): {fields}"
            )

        return {
            "temperature": float(fields[0]),
            "setpoint": float(fields[1]),
            "pump_temperature": float(fields[2]),
            "pwm": float(fields[3]),
            "fan_pwm": float(fields[4]),
            "tank_level_low": float(fields[5]),
            "status": int(fields[6]),
            "faults": int(fields[7]),
        }

    def is_open(self):
        return self.ser.is_open

if __name__ == '__main__':

    for port in list_ports.comports():
        if port.serial_number == CHILLER_SERIAL_NUMBER:
            chiller = TCubeChiller(port.device, baudrate=CHILLER_SERIAL_BAUDRATE)
            chiller.connect()

    print("Identification:", chiller.identify())

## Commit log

2026-06-10 pip install driver dependencies
2026-06-12 .gitignore added to ignore the drivers and documentation folders
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2026-06-12 Driver to control solenoid valve created.
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2026-06-15 test suite to stand in for Slotis Scheduler client/server
2026-06-15 Deprecated client file for camera
2026-06-15 Added inficon gauge standin and camera client IP and ports
2026-06-16 Add docs for all devices + sketch of hardware connections
2026-06-18 Correction for INFICON gauge PSG
    [inficon.py]
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2026-06-22 removed self.ser as none causing error
    [chiller.py]
2026-06-23 Create scheduler emulator + non blocking thread for PDU client + schematics updated
2026-06-23 Added client to control puumps and valve
2026-06-23 reads the outlet for the valve
2026-06-23 changed generic outlet to be labelled for the valve
2026-06-24 Created 30 minute buffer between pump down and scheduler time period
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2026-07-31 Utility to log pressure data to a csv file
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2026-08-04 Add other instruments sample commands for scheduler tests
2026-08-04 Improve status server emulator for storing status of devices in dict
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2026-08-05 Keep attributes formating consistent lower case and underscores
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2026-08-07 Correct bug linked to temperature setpoint
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2026-08-12 Added CAD files
    [4601N25_T-Slotted Framing Rail.SLDPRT, 47065T311_Black Corner Bracket.SLDPRT, Adapter_plate(with recess)-65mm dia_revised.SLDPRT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]
2026-08-17 Added CAD files + working on assemblies
    [3176T14_Vibration-Damping U-Bolt.SLDPRT, 4518K291_Quick-Clamp High-Vacuum Fitting.SLDPRT, 4518K522_Quick-Clamp High-Vacuum Fitting.SLDPRT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]
2026-08-18 updated step files
    [TELEDYNE_POWERPAK_BRACKET.SLDPRT, VCM-D1_1.STEP.SLDPRT, shutter_power_usb_assembly.SLDASM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]
2026-08-18 Updated telescope assembly
    [3136N173_T-Slotted Framing.SLDPRT, 3136N204_T-Slotted Framing.SLDPRT, 47065T472_T-Slotted Framing.SLDPRT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]
2026-08-19 Hopefully fixed mates
    [TELEDYNE_POWERPAK_BRACKET.SLDPRT, shutter_power_usb_assembly.SLDASM]
2026-08-19 Fixing mates
    [LRS-75-24.SLDASM, VCM-D1.SLDASM, shutter_power_usb_assembly.SLDASM]
2026-08-19 Updated t-slot cage
    [3136N181_T-Slotted Framing.SLDPRT, 3136N206_T-Slotted Framing.SLDPRT, 47065T562_T-Slotted Framing.SLDPRT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]
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2026-08-21 Power consumption evaluation
    [POWER_CONSUMPTION.ods]
2026-08-21 Structural Bracket adaptor
    [T-Slotted_Framing_2_to_3_Corner_Bracket_Adaptor.SLDPRT]
2026-08-21 Update on CAD model
    [3136N194_T-Slotted Framing.SLDPRT, 3136N206_T-Slotted Framing.SLDPRT, 3136N208_T-Slotted Framing.SLDPRT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]
2026-08-24 Work in progress on CAD assembly
    [3136N344_T-Slotted Framing.SLDPRT, 47065T451_Black Diagonal Brace.SLDPRT, CAGE_SUBASSEMBLY.SLDASM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]
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2026-08-25 Add command for SSH tunnel to kpno slotis
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2026-09-02 Update power consumption budget
    [POWER_CONSUMPTION.ods]
2026-09-03 V2 assembly CAD
    [1750-0899 SOPHIA-XO 2048 6 inch.STEP_1.SLDASM, 1750-0903 SOPHIA-XO 2048 6 inch.STEP_1.SLDASM, 2100-0462 SOPHIA-XO 2048 6 inch.STEP_1.SLDPRT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]
2026-09-03 Progress on V2 CAD design
    [5253T11_Stainless Steel Screw-In Cable Tie Mount.SLDPRT, 6575N477_T-Slotted Framing Rail.SLDPRT, 9088K28_Flanged Ultra-High-Vacuum Fitting for Stainless Steel 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]
2026-09-04 Even more progress on CAD design
    [47065T1_T-Slotted Framing_8in.SLDPRT, 47065T335_Diagonal Brace Ends for 2 High Double-Quad Rail T-Slotted Framing.SLDPRT, CAGE_SUBASSEMBLY_V2.SLDASM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]
2026-09-10 Progress on CAD
    [90deg_bracket_tslot.SLDPRT, Adapter_plate(with recess)-65mm dia_revised.SLDPRT, AdjustmentScrew.SLDPRT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]
2026-09-14 Updated CAD for vacuum tubing strut
    [3225T63_Vibration-Damping Loop Clamp.SLDPRT, CAGE_SUBASSEMBLY_V2.SLDASM, NEW_tubing_support_frame.SLDPRT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]
2026-09-14 V2 shutter power assembly + some CoMs
    [3136N171_T-Slotted Framing.SLDPRT, 3136N172_T-Slotted Framing.SLDPRT, 91075A256_Male-Female Threaded Hex Standoff.SLDPRT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]
2026-09-16 Bracket + mounting system on extrusion
    [47065T1_T-Slotted Framing_2in.SLDPRT, 47065T239_Silver Corner Bracket.SLDPRT, 47065T489_T-Slotted Framing_2in.SLDPRT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]
2026-09-16 Added brackets to the framing
    [3136N157_T-Slotted Framing.SLDPRT, 3136N159_T-Slotted Framing.SLDPRT, 3136N161_T-Slotted Framing.SLDPRT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]
2026-09-18 SuperLOTIS assembly FINAL (hopefully)
    [47065T736_Silver Gusset Bracket.SLDPRT, 90deg_bracket_tslot.SLDPRT, 91145A222_Nylon Flat Edge Insulating Sleeve Washers.SLDPRT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]
2026-09-22 Updated CAD of SuperLOTIS
    [3136N157_T-Slotted Framing.SLDPRT, 3136N159_T-Slotted Framing.SLDPRT, 3136N171_T-Slotted Framing.SLDPRT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]
2026-09-22 V2.5 put 1 by 1 instead of 2 by 1
    [47065T1_T-Slotted Framing.SLDPRT, 47065T1_T-Slotted Framing_10in.SLDPRT, 47065T335_Diagonal Brace Ends for 2 High Double-Quad Rail T-Slotted Framing.SLDPRT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]
2026-09-23 Last update with enclosure before meeting
    [47065T313_T-Slotted Framing.SLDPRT, 47065T832_T-Slotted Framing.SLDPRT, CAGE_SUBASSEMBLY_V2.SLDASM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]
2026-09-25 Updated order list + standoffs + started drawings
    [47065T313_T-Slotted Framing.SLDPRT, 47065T832_T-Slotted Framing.SLDPRT, 90deg_bracket_tslot.SLDDRW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]
2026-09-26 update to tubro bracket
    [Turbo_bottom_bracket.SLDDRW, Turbo_bottom_bracket.SLDPRT, Turbo_bracket_assembly.SLDASM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]
2026-09-26 Drawings + spreadsheet for list of parts to make
    [90deg_bracket_tslot.SLDDRW, 90deg_bracket_tslot.SLDPRT, 90deg_bracket_tslot.STL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]
2026-10-20 Bracket for TELEDYNE power supply + camera tubing
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
